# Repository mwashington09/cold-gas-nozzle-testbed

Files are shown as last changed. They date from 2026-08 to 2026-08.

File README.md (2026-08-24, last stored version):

# Cold-Gas Nozzle Testbed

## My Goal

- **Design, build, and instrument a cold-gas thrust stand to determine whether an aerospike nozzle outperforms a conventional bell nozzle at off-design pressure ratios**

## Software and Skills

- **SOLIDWORKS**
- **Python**
- **Arduino / Embedded C++**
- **Fused Deposition 3D Printing**
- **Sensor Instrumentation and Calibration**
- **Soldering and Circuit Assembly**
- **Compressible Flow Analysis**

## Constraints

- **All nozzles share a common throat area of 12.6 mm² and expansion ratio of 4 so that geometry is the only variable**
- **Cold gas only — no combustion, isolating aerodynamic performance from thermal effects**
- **All components fabricated or assembled from commercially available parts**
- **Test conditions limited to 40, 80, and 120 psi regulator settings**

## Nozzle Design

Three geometries were designed to identical throat area and expansion ratio, differing only in the diverging section. Conical, bell, and aerospike were fabricated in PLA on an AnkerMake M5C. A truncated plug geometry was designed but not tested.

The aerospike spike contour was generated using a Python implementation of **Angelino's approximate method** for axisymmetric plug nozzles. For CO₂ at γ = 1.29 and ε = 4, this produces:

| Parameter | Value |
|---|---|
| Design exit Mach number | 2.758 |
| Cowl lip radius | 4.000 mm |
| Throat flow angle | 50.6° inward from axis |
| Annular throat gap | 0.522 mm |
| Spike length | 10.69 mm |

Nozzle Geometries
<!-- ![Nozzle geometries](images/nozzles.jpg) -->

Aerospike CAD Model
<!-- ![Aerospike](images/aerospike_cad.jpg) -->

## Test Stand

The thruster fires vertically upward, aligning the thrust vector with the load cell's sensitive axis and allowing the static weight of the plenum assembly to be removed by taring before each run.

- **Plenum epoxied into a hexagonal recess in a 3D-printed upper plate**
- **Single-point load cell mounted between upper and lower plates**
- **Standoffs at each mounting point preserving beam deflection clearance**
- **Supply hose routed with slack to prevent parasitic force transmission**

Assembled Test Stand
<!-- ![Test stand](images/test_stand.jpg) -->

## Gas System

CO₂ cylinder → CGA-320 adapter → adjustable regulator → solenoid valve → plenum → nozzle

- **12 V normally-closed brass solenoid valve, 2.5 mm internal orifice**
- **Driven through an IRLZ44N MOSFET with flyback diode protection**
- **Brass tee-fitting plenum with dedicated sensor ports**
- **Garden-hose-thread nozzle interface for tool-free geometry swaps**

Plenum Assembly
<!-- ![Plenum](images/plenum.jpg) -->

## Instrumentation

Six channels on an Arduino Mega 2560:

| Measurement | Device |
|---|---|
| Thrust | 1 kg load cell, HX711 24-bit amplifier |
| Propellant mass | 5 kg load cell, HX711 |
| Chamber pressure | 150 psi transducer, 0.5–4.5 V output |
| Plenum gas temperature | K-type thermocouple, MAX31855 |
| Cylinder temperature | K-type thermocouple, MAX31855 |
| Ambient conditions | BME280 |

Both load cells were calibrated against a 370 g reference mass. Thrust resolution reached 0.021 gf per ADC count with a noise floor below 1 gf.

Breadboard and DAQ Wiring
<!-- ![Electronics](images/electronics.jpg) -->

## Data Acquisition

The Arduino tares both load cells and captures the pressure transducer zero offset at startup, then waits for a fire command over serial. On command it logs a pre-fire baseline, opens the solenoid for a fixed 2-second burn, and continues logging through the blowdown decay.

Thermocouples are sampled before and after the burn rather than during, since polling them mid-burn would throttle the load cell sampling rate.

A Python script on the host receives the stream, prompts for run metadata, and writes a timestamped CSV per firing.

## Results

**27 test firings** across three geometries at three supply pressures, three replicates each.

| Condition | Replicate thrust (gf) |
|---|---|
| Bell, 80 psi | 139.2, 141.0, 133.9 |
| Aerospike, 80 psi | 117.6, 107.7, 109.5 |
| Aerospike, 120 psi | 143.2, 146.9, 147.4 |

- **Within-burn scatter below 1% of the mean for the majority of runs**
- **Thrust increased monotonically with supply pressure for every geometry**
- **Bell produced higher thrust than aerospike at every matched condition**

Representative Thrust Trace
<!-- ![Thrust trace](images/thrust_trace.png) -->

Thrust vs. Supply Pressure
<!-- ![Thrust comparison](images/thrust_comparison.png) -->

## The Flow Regime Finding

Measured plenum pressure never exceeded **0.5 psi** at any regulator setting, showing no correlation with supply pressure — despite thrust and propellant mass loss both confirming substantial gas flow.

The cause was isolated through controlled testing:

- **The pressure transducer was verified against a known reference on the bench**
- **The solenoid was held open continuously while plenum pressure was monitored, confirming pressure stayed near ambient under sustained flow**
- **The valve orifice measures 2.5 mm; the nozzle throat measures 4.0 mm**

With an exit less restrictive than the inlet, gas passes through the plenum as fast as it is admitted and no pressure accumulates. Chamber volume affects only how long steady state takes to reach, not what that steady state is.

**The nozzles were therefore operating as subsonic flow restrictions rather than de Laval nozzles.** Without a choked throat there is no supersonic expansion, and the mechanism responsible for aerospike altitude compensation was never present. Measured differences between geometries reflect effective flow area and internal losses, not expansion efficiency.

This was identified using the project's own instrumentation.

## Limitations

- **Flow regime** — the system operated below choked conditions, so the data does not support conclusions about supersonic expansion or altitude compensation
- **Throat area verification** — printed dimensions were not measured against design geometry, which matters most for the aerospike's 0.522 mm annular gap
- **Supply conditions** — cylinder temperature dropped measurably during firing, and back-to-back runs showed reduced mass flow as the cylinder cold-soaked

## Future Work

- **Reduce throat diameter below the 2.5 mm valve orifice to restore choked flow**
- **Directly measure the printed aerospike annular gap**
- **Test the truncated plug geometry**
- **Compare measured performance against CFD**

## Repository Contents

```
├── firmware/     Arduino sketches - main DAQ plus sensor bring-up and diagnostics
├── analysis/     Python serial logger and analysis notebook
├── data/         Raw CSV output from all test firings
├── cad/          Nozzle geometry - STL and SOLIDWORKS files
└── images/       Photos of the apparatus
```

Each CSV contains a metadata header followed by time-series columns: elapsed milliseconds, commanded valve state, thrust in grams-force, cylinder mass in grams, and chamber pressure in psi.

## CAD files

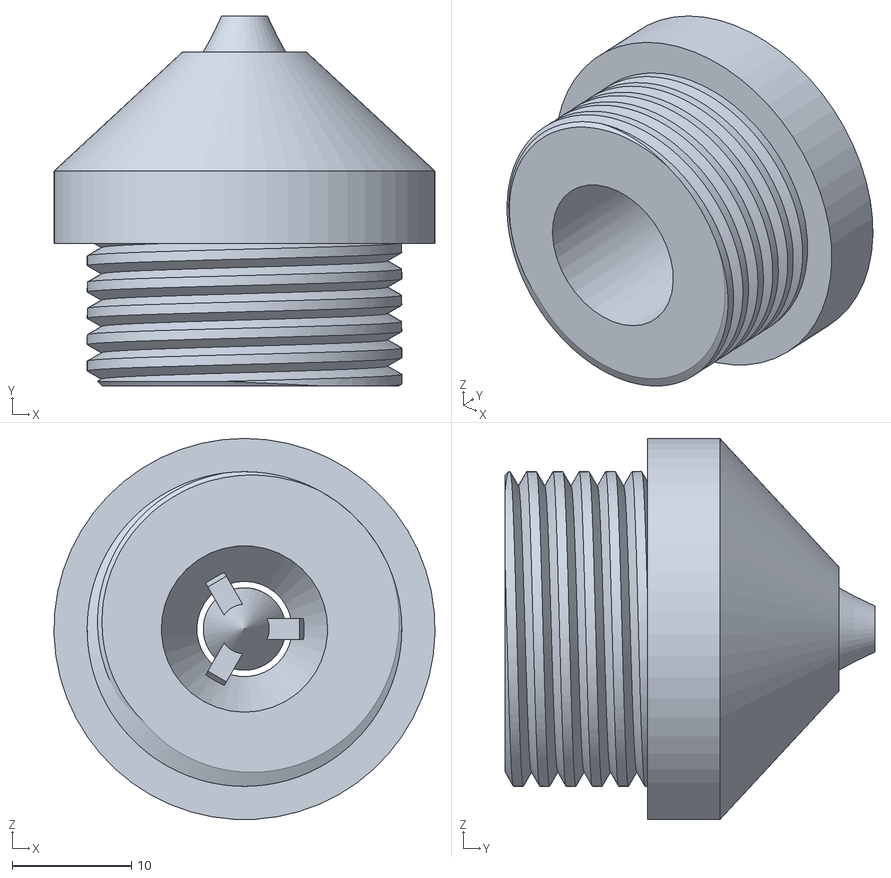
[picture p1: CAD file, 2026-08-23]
cad/Plug Shaped Nozzle.STL
32.0 x 31.0 x 32.0

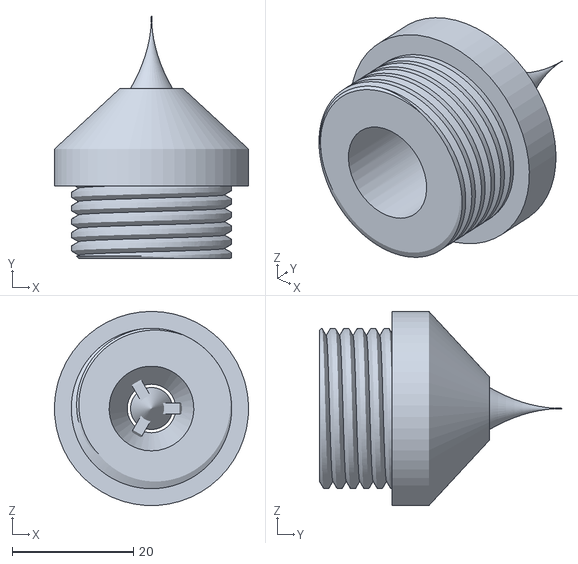
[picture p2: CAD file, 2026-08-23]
cad/Aerospike shaped nozzle.STL
32.0 x 39.9 x 32.0

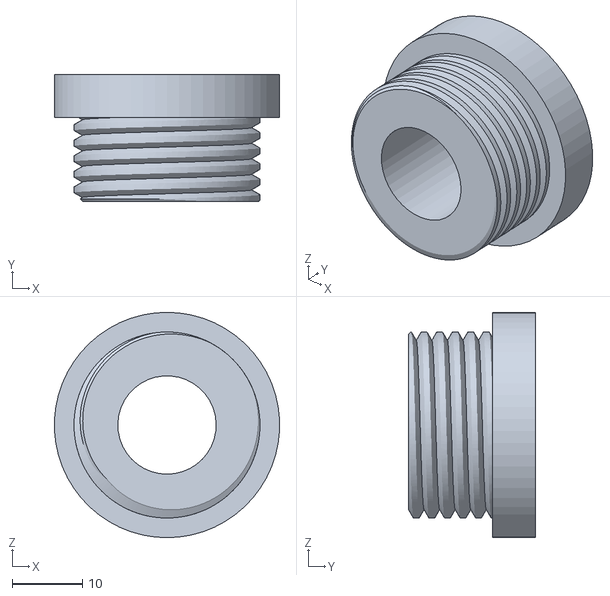
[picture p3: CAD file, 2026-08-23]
cad/GHT male part.STL
32.0 x 18.0 x 32.0

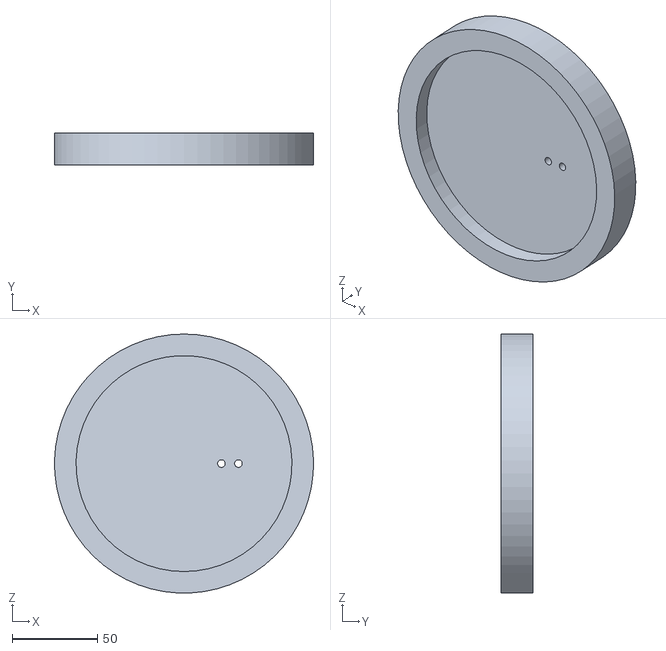
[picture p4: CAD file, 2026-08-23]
cad/Bottom Plate.STL
152.3 x 19.1 x 152.3

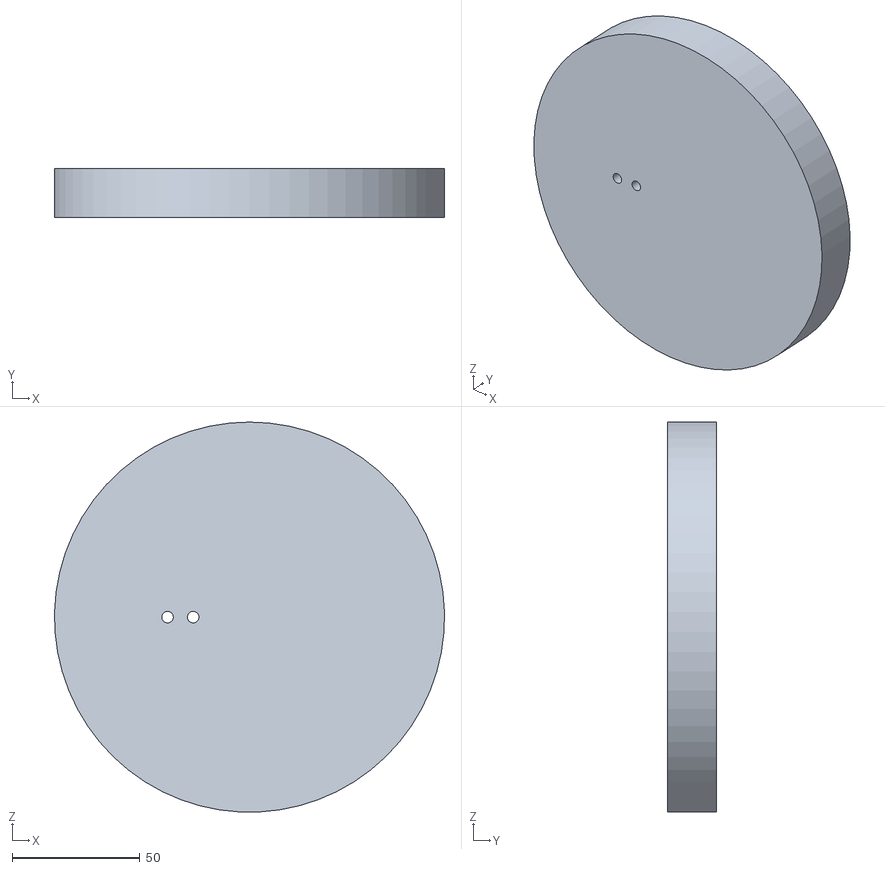
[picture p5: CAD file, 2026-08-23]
cad/Plate 1.STL
152.3 x 19.1 x 152.3

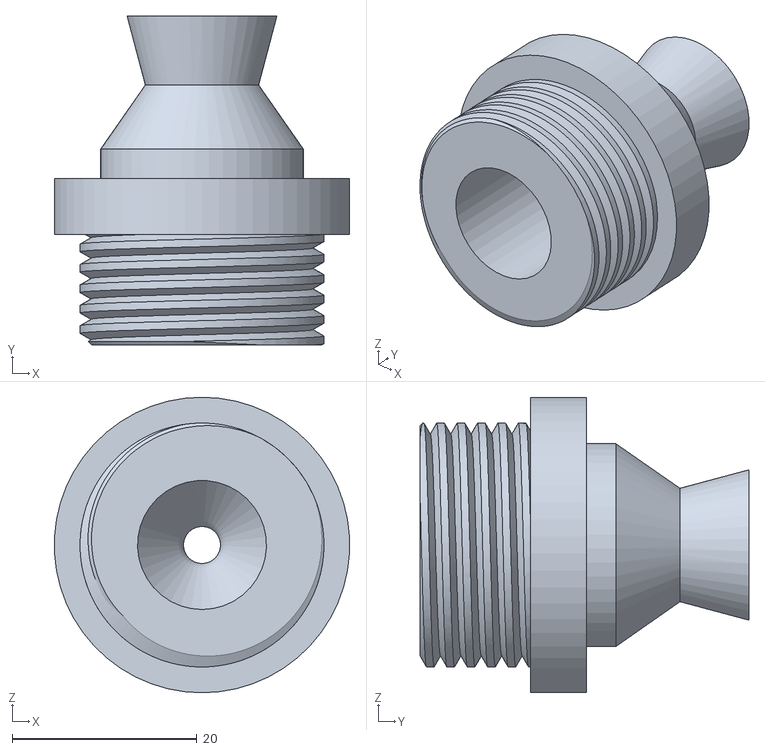
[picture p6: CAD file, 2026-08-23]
cad/Conical shaped nozzle.STL
31.9 x 35.6 x 32.0

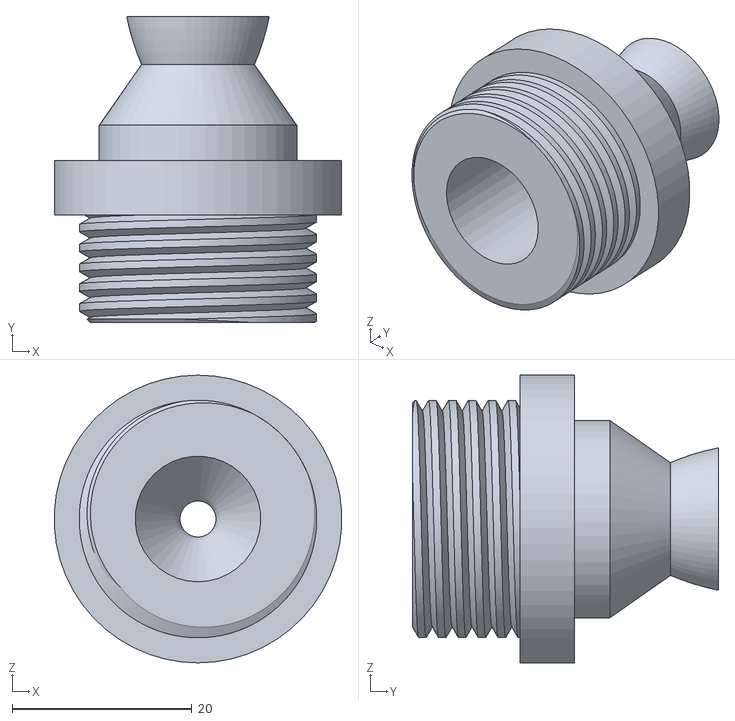
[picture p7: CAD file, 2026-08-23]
cad/Bell shaped nozzle.STL
31.9 x 34.0 x 32.0

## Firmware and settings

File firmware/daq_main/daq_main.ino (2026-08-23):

#include "HX711.h"
#include <Adafruit_MAX31855.h>
#include <Adafruit_BME280.h>

const float THRUST_CAL = 48.343;
const float TANK_CAL = 411.030;
const float PSI_MAX = 150.0;
const int BURN_MS = 2000;
const int PRE_MS = 500;
const int POST_MS = 1500;

HX711 thrust;
HX711 tank;
Adafruit_MAX31855 tcPlenum(52, 53, 50);
Adafruit_MAX31855 tcTank(52, 49, 50);
Adafruit_BME280 bme;

float psiZero = 0;
bool bmeOK = false;

void setup() {
  Serial.begin(115200);
  pinMode(7, OUTPUT);
  digitalWrite(7, LOW);
  thrust.begin(3, 2);
  thrust.set_scale(THRUST_CAL);
  tank.begin(5, 4);
  tank.set_scale(TANK_CAL);
  tcPlenum.begin();
  tcTank.begin();
  bmeOK = bme.begin(0x76) || bme.begin(0x77);
  Serial.println("# taring - hands off");
  delay(3000);
  thrust.tare(20);
  tank.tare(20);
  long z = 0;
  for (int i = 0; i < 50; i++) { z += analogRead(A0); delay(5); }
  psiZero = z / 50.0;
  Serial.print("# ambient_hPa,");
  Serial.println(bmeOK ? bme.readPressure() / 100.0 : 0.0);
  Serial.print("# ambient_C,");
  Serial.println(bmeOK ? bme.readTemperature() : 0.0);
  Serial.println("# send f to fire");
}

void logRow(unsigned long t0, bool valveOpen) {
  Serial.print(millis() - t0);
  Serial.print(",");
  Serial.print(valveOpen ? 1 : 0);
  Serial.print(",");
  Serial.print(thrust.get_units(1), 2);
  Serial.print(",");
  Serial.print(tank.get_units(1), 2);
  Serial.print(",");
  float v = analogRead(A0) * (5.0 / 1023.0);
  float vz = psiZero * (5.0 / 1023.0);
  Serial.println((v - vz) * (PSI_MAX / 4.0), 2);
}

void loop() {
  if (!Serial.available()) return;
  char c = Serial.read();
  while (Serial.available()) Serial.read();
  if (c != 'f' && c != 'F') return;
  double p0 = tcPlenum.readCelsius();
  double k0 = tcTank.readCelsius();
  Serial.println("ms,valve,thrust_g,tank_g,psi");
  unsigned long t0 = millis();
  while (millis() - t0 < PRE_MS) logRow(t0, false);
  digitalWrite(7, HIGH);
  while (millis() - t0 < PRE_MS + BURN_MS) logRow(t0, true);
  digitalWrite(7, LOW);
  while (millis() - t0 < PRE_MS + BURN_MS + POST_MS) logRow(t0, false);
  Serial.print("# plenum_C_start,");
  Serial.println(p0);
  Serial.print("# tank_C_start,");
  Serial.println(k0);
  Serial.print("# plenum_C_end,");
  Serial.println(tcPlenum.readCelsius());
  Serial.print("# tank_C_end,");
  Serial.println(tcTank.readCelsius());
  Serial.println("# done");
}

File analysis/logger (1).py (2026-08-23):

"""
Serial logger for the cold-gas nozzle testbed.

Connects to the Arduino running daq_main.ino, waits for the tare sequence
to complete, triggers a firing, and writes the returned CSV stream to disk.

Filenames are generated from the nozzle geometry, regulator setting, and
run number entered at the prompts.

Requires: pyserial  (pip install pyserial)
"""

import serial
import time
import csv

PORT = 'COM7'
BAUD = 115200
OUT_DIR = r"C:\Documents_nozzledata"

nozzle = input("Nozzle: ").strip()
psi = input("Pressure (psi): ").strip()
run = input("Run number: ").strip()

fname = rf"{OUT_DIR}\{nozzle}_{psi}psi_run{run}.csv"

ser = serial.Serial(PORT, BAUD, timeout=2)
time.sleep(2)

# Wait for the Arduino to finish taring and signal it is ready
print("Waiting for tare...")
meta = []
while True:
    line = ser.readline().decode(errors='ignore').strip()
    if not line:
        continue
    print(line)
    if line.startswith('#'):
        meta.append(line)
    if 'send f to fire' in line:
        break

input("Press ENTER to fire...")
ser.write(b'f')

# Read the burn data until the Arduino reports it is done
rows = []
header = None
while True:
    line = ser.readline().decode(errors='ignore').strip()
    if not line:
        continue
    if line.startswith('#'):
        meta.append(line)
        if 'done' in line:
            break
    elif header is None:
        header = line.split(',')
    else:
        rows.append(line.split(','))

ser.close()

# Metadata lines are written first, then the header and data rows
with open(fname, 'w', newline='') as f:
    w = csv.writer(f)
    for m in meta:
        w.writerow([m])
    w.writerow(header)
    w.writerows(rows)

print(f"Saved {fname} - {len(rows)} samples")
